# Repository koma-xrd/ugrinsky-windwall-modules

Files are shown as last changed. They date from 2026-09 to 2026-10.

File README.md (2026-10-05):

# Ugrinsky Wind Wall V5

> **AI-assisted design:** This model and its documentation were developed with
> generative AI assistance. They remain an unvalidated prototype and require
> physical fit, strength, weather, rotation, and electrical testing before use.

A parametric CadQuery project for a seven-stage vertical-axis rotor and an
experimental axial-flux generator mounted between two timber rails. The repository
contains editable CAD source, verified geometry exports, assembly drawings, and
complete assembly and coil-experiment manuals in six languages.

**V5 is a prototype awaiting physical validation.** Geometry checks do not establish
power output, a safe maximum speed, fatigue life, weather resistance, or suitability
for unattended operation. Begin with fit coupons and a guarded workshop test rig.
The generator must not be connected directly to a 48 V lead-acid battery.

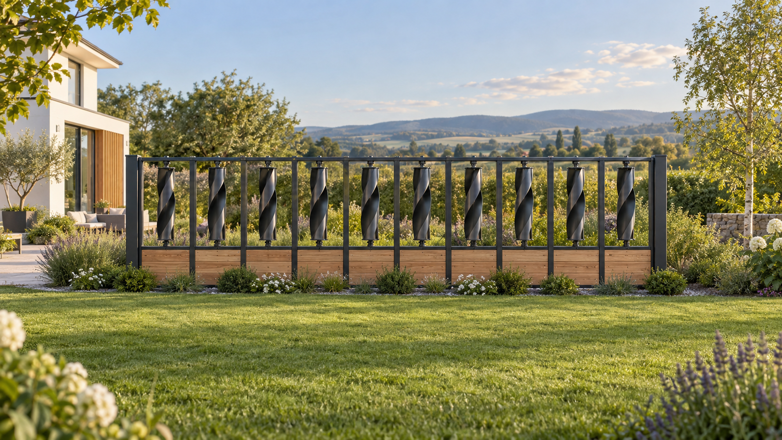
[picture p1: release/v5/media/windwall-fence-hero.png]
Realistic concept of a ten-rotor Ugrinsky fence beside a modern home and garden


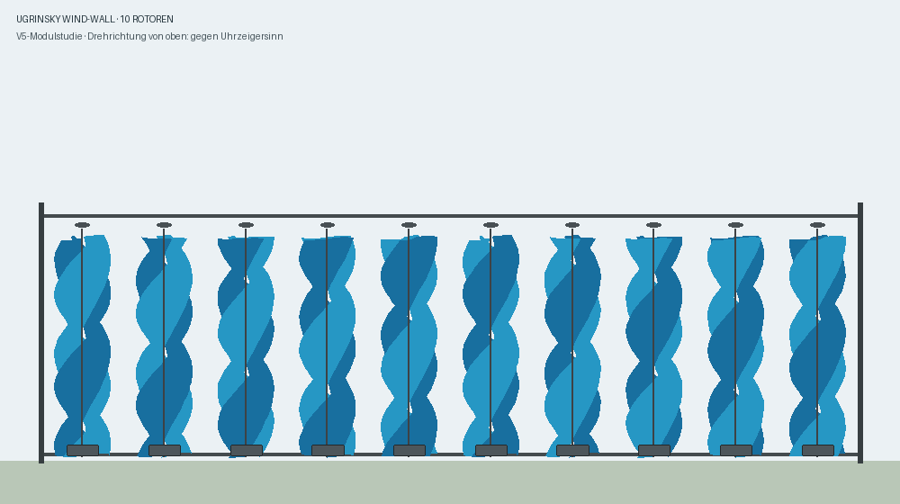
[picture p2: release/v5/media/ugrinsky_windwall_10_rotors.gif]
Animated ten-module Ugrinsky wall concept in a fence context


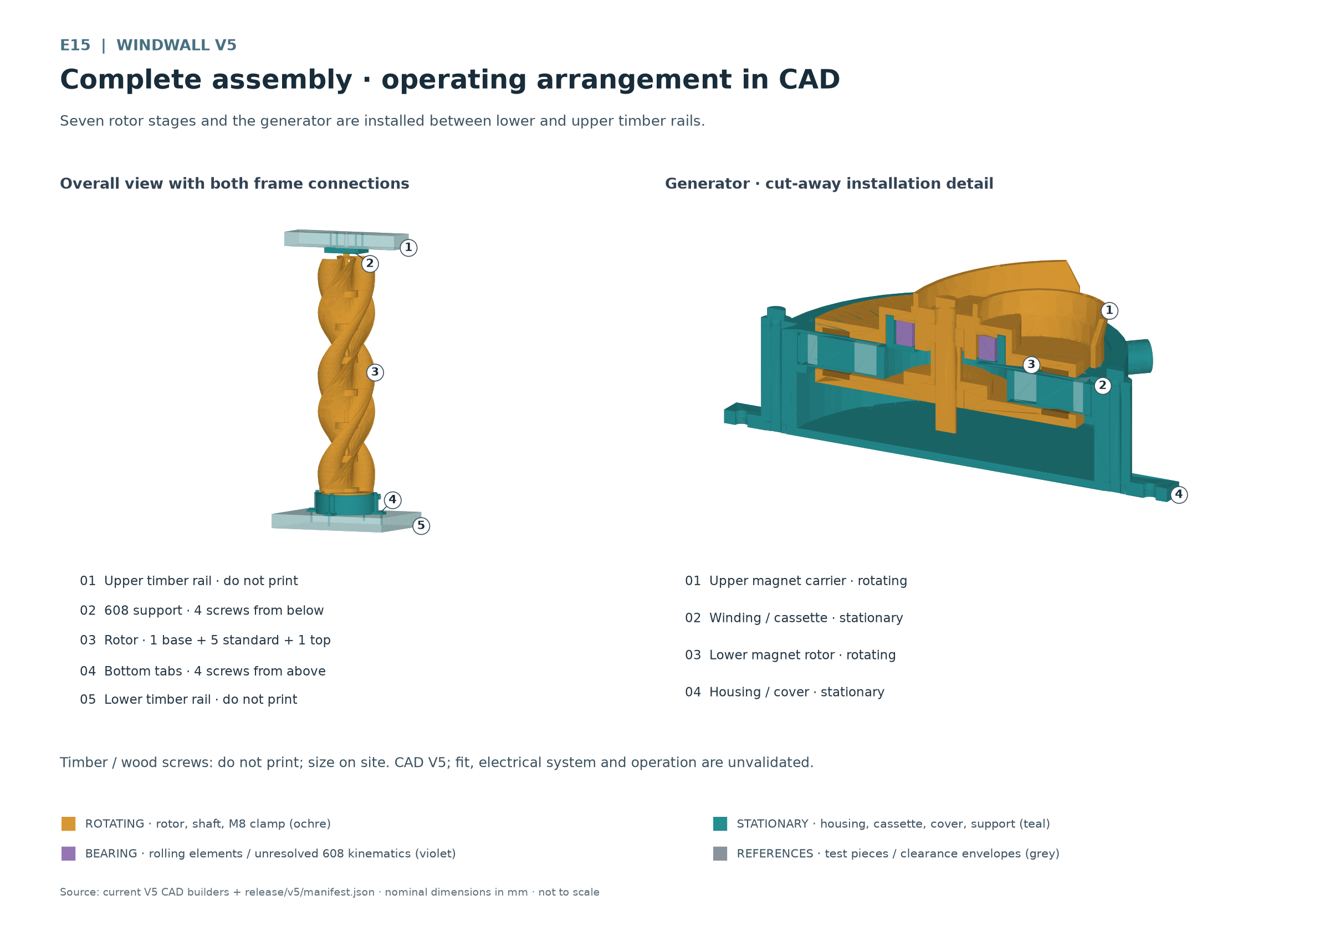
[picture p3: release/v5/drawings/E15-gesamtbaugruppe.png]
Complete V5 assembly between timber rails with rotating and stationary components distinguished


## Start here

The [release index](release/v5/release-index.json) is the complete portable inventory.
The [geometry manifest](release/v5/manifest.json) is authoritative for quantities,
dimensions, roles, file hashes, and CAD validation results.

| Assembly and experiment manual | Language |
| --- | --- |
| [English manual](release/v5/docs/Ugrinsky-Wind-Wall-V5-Manual-English.docx) | English · en-GB |
| [简体中文手册](release/v5/docs/Ugrinsky-Wind-Wall-V5-Manual-Chinese-Simplified.docx) | Simplified Chinese · zh-CN |
| [हिन्दी पुस्तिका](release/v5/docs/Ugrinsky-Wind-Wall-V5-Manual-Hindi.docx) | Hindi · hi-IN |
| [Manual en español](release/v5/docs/Ugrinsky-Wind-Wall-V5-Manual-Spanish.docx) | Spanish · es-ES |
| [Manuel en français](release/v5/docs/Ugrinsky-Wind-Wall-V5-Manual-French.docx) | French · fr-FR |
| [Deutsche Bauanleitung](release/v5/docs/Ugrinsky-Wind-Wall-V5-Bauanleitung.docx) | German source · de-DE |

Every manual preserves all 13 chapters, 11 tables and 15 current drawings. The five
translations include localized captions and complete alternative descriptions.
All manuals share the same canonical English E01-E15 engineering drawings.
Technical filenames remain unchanged.

The DOCX packages pass structural and accessibility checks. Rendering remains
blocked because bundled LibreOffice is unavailable on this Windows runtime; no PDF
or rendered-page approval is supplied. Pagination, clipping and Chinese/Hindi glyph
rendering require page-by-page visual review. No independent native-speaker review
is recorded.

## V5 architecture

The rotor has one base, five identical standard modules and one top module. Nominal
diameter is 122 mm, stage pitch is 70 mm and aerodynamic height is 490 mm. Each module
is one printed body with a 2 mm nominal blade wall. The base integrates the upper
magnet carrier. Adjacent stages have plain flush blade ends. The central bayonet
is the sole keyed torque interface; an M8 shaft and clamping hardware complete
the rotating assembly.

The lower magnet rotor has a flat 5 mm carrier print surface, a raised central
boss with a bottom-open M8 nut pocket, and an upper integral sleeve. Print the flat
carrier face on the bed; the pocket remains accessible from below. The rotor runs
inside the closed-bottom housing, below the stationary
coil cassette. A keyed shoulder seats the cassette; a screwed cover retains it
from above. The 51105 thrust bearing transfers rotor weight to the stationary cover
and housing. The upper 608 bearing provides radial guidance in a separate support
attached beneath the upper timber rail.

The base includes a 54 mm rotating labyrinth cup around the stationary 51105
bearing-seat ring. Its 49 mm internal diameter leaves 0.4 mm nominal radial
clearance, and its top cap leaves 0.25 mm nominal axial clearance above the ring.
Check free rotation and the printed clearances before running the rotor. This
shield does not establish waterproofing or weather resistance.

| Rotates with the shaft | Remains stationary | Bearing motion |
| --- | --- | --- |
| Base and integrated upper magnet carrier | Housing and mounting tabs | 51105 shaft washer rotates with the base |
| Five standard modules and top module | Coil and keyed cassette | 51105 housing washer stays in the cover |
| Lower magnet rotor, integral spacer sleeve and both magnet rings | Cover and its four M4 fasteners | 51105 rolling elements have their own motion |
| M8 rod, three nuts and top washer | Upper support and timber frame | 608 inner ring follows the shaft; outer ring stays in its support |

Purple bearing envelopes do not resolve individual rolling-element motion. Grey
timber and screw envelopes are references, not printable parts or structural approvals.

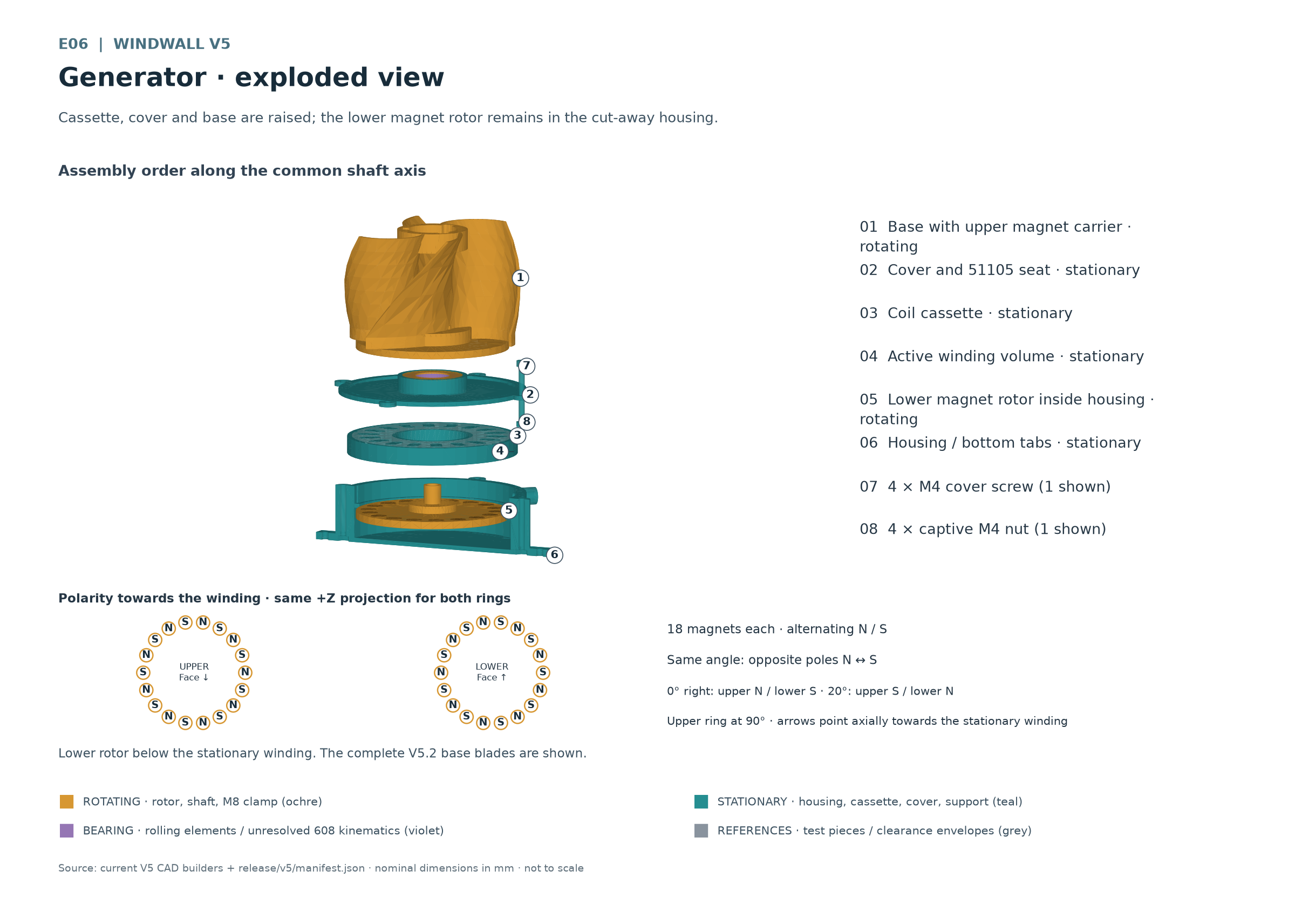
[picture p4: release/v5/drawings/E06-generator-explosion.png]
Generator explosion with top access and the lower rotor inside the housing


## Printed parts and hardware

One complete V5 needs **12 printed bodies from 8 unique STL files**. Production STLs
are in [release/v5/stl](release/v5/stl/); each has a same-stem STEP in
[release/v5/step](release/v5/step/). STLs sit at print Z = 0, which does not choose
the best support strategy or printing orientation.

| Qty | STL filename | Function | Motion |
| --- | --- | --- | --- |
| 1 | `base_rotor_module.stl` | Base, integrated upper magnet carrier and bearing pilot | Rotating |
| 5 | `standard_rotor_module.stl` | Intermediate rotor stages | Rotating |
| 1 | `top_rotor_module.stl` | Final stage and reinforced top clamp seat | Rotating |
| 1 | `lower_magnet_rotor.stl` | Lower carrier with integral 12 × 17.85 mm shaft sleeve | Rotating |
| 1 | `generator_housing.stl` | Closed cup, cassette shoulder, cable outlet and mounting tabs | Stationary |
| 1 | `coil_cassette.stl` | Removable carrier with 18 open serpentine guides and anti-rotation key | Stationary |
| 1 | `generator_cover.stl` | Cassette retention and 51105 housing seat | Stationary |
| 1 | `top_support.stl` | Upper 608 bearing support | Stationary |

Print the nine [coupon bodies](release/v5/coupons/) first:
`magnet_pocket_coupon.stl`, `51105_outer_seat_coupon.stl`, `25mm_pilot_coupon.stl`,
`608_seat_coupon.stl`, `coil_cassette_segment_coupon.stl`, `bayonet_male.stl`,
`bayonet_female.stl`, `joint_male.stl`, and `joint_female.stl`. Each also has a STEP.
Cut the male cassette arc free flush with its plate and deburr it before comparison.

| Qty | Purchased item | Selection notes |
| --- | --- | --- |
| 1 | M8 threaded rod | Extended shaft envelope 555.8 mm; establish actual cut length by dry assembly |
| 3 | M8 nuts | Two torque-transmitting nuts and one upper clamping nut |
| 1 | Top M8 washer | Nominal 24 mm outside diameter × 2 mm thickness |
| 36 | Magnets | Two rings of 18; target 10 × 2 mm; measure coating and actual dimensions |
| 1 | Complete 51105 thrust bearing | 25 × 42 × 11 mm, including both washers and rolling elements |
| 1 | 608 radial bearing | 8 × 22 × 7 mm |
| 4 each | M4 cover screws and captive hex nuts | Separate from the four frame screws; select length and head from the real grip |
| 4 | Lower timber screws | Reference 4 × 30 mm, flat head Ø9; site-specific selection required |
| 4 | Upper timber screws | Reference 4 × 40 mm; site-specific selection required |

Also provide enamelled copper wire, insulated leads, suitable soldering and
insulation materials, tested magnet retention, strain relief and edge protection.
Test compatibility with enamel, magnet coating and print material before adhesive
or potting. Nominal hardware envelopes are not procurement or load-rating approvals.

## Printing and bearing fits

Start with **PLA on a Bambu P2S with a 0.4 mm nozzle**. Use the actual filament's
profile. A 0.20 mm layer height is an unvalidated starting point; set temperature,
cooling, walls, infill and supports from coupons and the complete slicer preview.
Confirm continuous toolpaths in the 2 mm blade wall. Bayonet roofs and undercuts
need verified bridges or removable supports. Keep support residue and elephant
foot off mating surfaces. Compare normal and inverted base orientations because
its installed magnet pockets face downwards.

Print coupons, then a real two-stage joint, then the full set. Record joining force,
cracks, seam alignment and play. **ASA is the intended later outdoor material trial**;
repeat fit, warping, retention and load tests after changing material. ASA alone does
not establish weatherproofing or long-term outdoor suitability. Follow the actual
filament and printer processing and ventilation instructions.

| Interface | Current CAD nominal | Coupon choices |
| --- | --- | --- |
| 51105 stationary outer seat | Ø42.2 mm × 11.2 mm seat depth | Ø42.0 / 42.2 / 42.4 mm |
| 51105 rotating base pilot | Ø24.8 mm | Ø24.6 / 24.8 / 25.0 mm |
| 608 upper support seat | Ø22.2 mm × 7.2 mm seat depth | Ø22.0 / 22.2 / 22.4 mm |
| Magnet pocket | Ø11.0 mm × 2.0 mm deep | Ø10.8 / 11.0 / 11.2 mm |
| Cassette radial clearance | Verify keyed fit and cover retention | 0.30 / 0.35 / 0.40 mm |

These are fit experiments, not approved press fits. The 51105 housing washer stays
in the cover and the shaft washer rotates with the base; both raceways face the
rolling elements. Identify parts by actual geometry and manufacturer markings.
Apply fitting force only to the ring or washer being seated.

The upper 608 outer ring stays in its support; timber closes the upward-open seat.
An M8 threaded rod is not a ground bearing journal. Any locally prepared running
surface needs measurement, controlled machining and rechecking of diameter, runout
and remaining section. Avoid a second axial clamp at the upper bearing. A printed
shaft guide sleeve is not specified.

## Magnet polarity and gap reference planes

Each ring has 18 coil-facing poles. Alternate **N S N S** around the upper ring.
At the same angle in a common +Z projection, the lower coil-facing pole is opposite:
upper N faces lower S, then upper S faces lower N. Mark a reference pocket and check
faces after flipping a carrier. Confirm retention independently before each rotation
test; open pockets alone do not establish centrifugal retention.

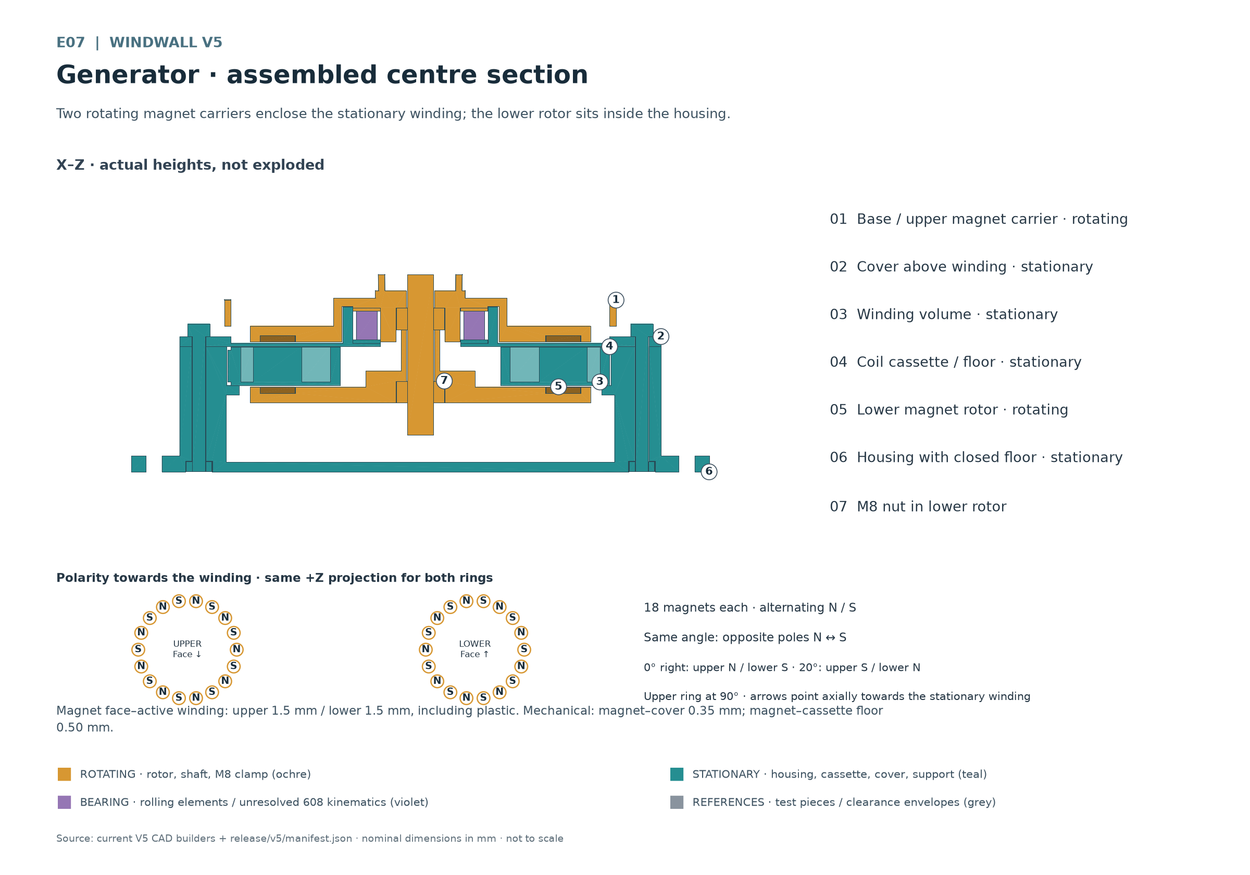
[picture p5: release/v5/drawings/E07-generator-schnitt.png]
Generator section showing rotating magnet rings around the stationary winding and both gap reference planes


| Distance | Nominal | Reference surfaces |
| --- | --- | --- |
| Upper magnetic distance | 1.5 mm | Upper magnet face to active winding face, including cover plastic |
| Lower magnetic distance | 1.5 mm | Lower magnet face to active winding face, including cassette-floor plastic |
| Upper mechanical clearance | 0.35 mm | Magnet face to cover membrane |
| Lower mechanical clearance | 0.50 mm | Magnet face to cassette floor |
| Membrane and cassette-floor thickness | 1.00 mm each | Plastic included in the magnetic distances |
| Cassette upward retention travel | 0.15 mm | Cassette top to cover underside |

The 1.5 mm values require flush or recessed magnets. Adhesive, protrusion, winding
height, axial float and runout can reduce the minimum clearance. Measure both gaps
over a full hand revolution and with available axial play. Contact-free CAD does not
prove clearance under load. Correct rubbing; never use higher speed to clear it.

## Assembly sequence

Use the full manual for tooling, checks and service. The essential order is:

1. Measure hardware, validate coupons and check magnet retention and polarity.
   Prepare an insulated, removable test coil and lead strain relief.
2. Seat four captive M4 nuts. Put the lower rotor, its M8 torque nut, shaft and
   integral sleeve inside the housing with magnet faces upwards. Keep nut and shaft clear of the floor.
3. Lower the cassette onto its shoulder, engage its key, align cable openings and
   route the protected cable.
4. Fit the stationary cover and tighten four M4 screws evenly in a crossing sequence.
   No PLA tightening torque is validated.
5. Install the 51105 housing washer, rolling elements and shaft washer correctly.
   Lower the base and upper torque nut, magnet faces down, controlling attraction
   with a fixture.
6. Check hand rotation and gaps. Add five standard modules and the top. Align the
   bayonet insertion windows, lock counterclockwise viewed from above, verify
   flush blade contact and inspect every latch. The dedicated bayonet fit uses
   0.20 mm nominal radial and 0.18 mm nominal axial clearance; its enlarged latch
   flank is intended to remain practically permanent after engagement. Reverse
   disassembly can damage the latch or module.
7. Fit the top washer directly on the flat upper plate and add the M8 nut; finish clamp adjustment before the upper bearing
   support. Do not bind stationary parts or bearings.
8. Fasten the housing's four tabs to the lower timber from above. Fit the 608 and
   fasten the upper support from below with four screws. Align both bearing axes;
   confirm full shaft engagement, end clearance and free rotation again.

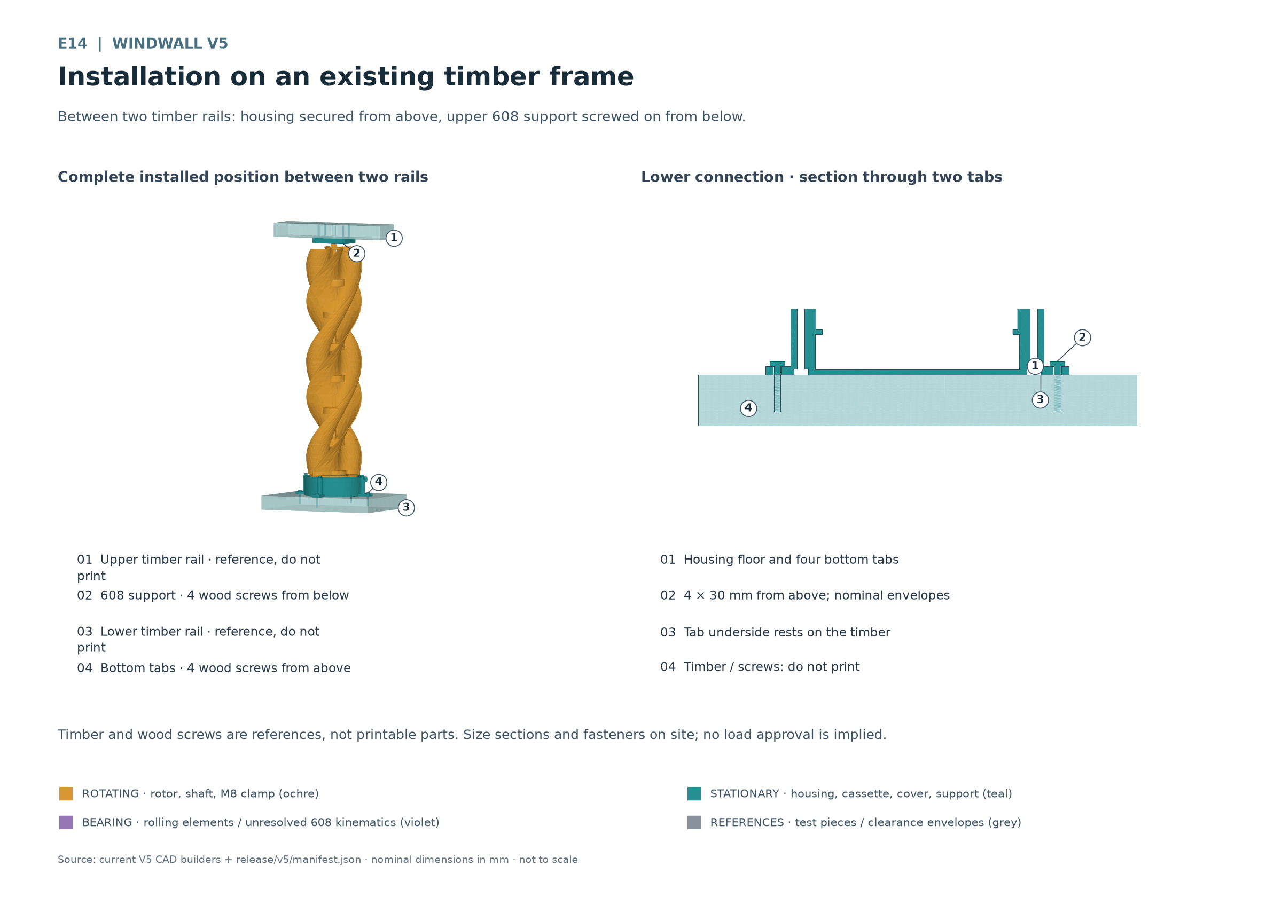
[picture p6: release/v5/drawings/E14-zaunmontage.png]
Fence mounting with lower housing screws downwards and upper support screws upwards


E14 timber sections and screw envelopes are examples. Frame strength, fixings,
edge distances and wind loading require site-specific engineering. The upper
support guides radially; the lower 51105 carries the intended axial load. Service
the cassette from above with the rotor stack supported as one unit; routine coil
changes should not require unlocking its six permanent stage joints.

## Serpentine coil experiments

Route insulated wire continuously around the cassette's 18 rounded open guide
islands, alternating past the inner and outer side of each successive island.
For this series, **one complete circuit of all 18 guides is one turn**. Mark start A,
end B and the path. With a few repetitions and hand rotation, verify
that successive active sections add voltage. Reversed sections or incorrect poles
can cancel it; the cassette does not define a validated electrical winding.

| Measured wire | Test turns | Keep comparable |
| --- | --- | --- |
| Initial 0.18 mm enamelled copper wire | 20 / 40 / 80 | Path, direction, recorded speed and defined load |
| Each future measured wire diameter | Repeat 20 / 40 / 80 | Measure conductor and enamelled outside diameter separately |

Record cold resistance, winding height, minimum gaps, speed, AC open-circuit
voltage, load value, loaded voltage/current, ambient and coil temperature, duration,
noise and vibration. Use instruments suited to the waveform. Rectifiers or pulsed
currents require appropriate DC or true-power measurement. Higher open-circuit
voltage does not establish useful loaded output. There is no final turn count or
validated power rating; each derived winding needs a physical test.

Do not connect directly to a 48 V lead-acid battery, even experimentally. A future
charging design needs measured electrical behaviour, rectification, compatible
charge regulation, reverse-current blocking, cable and short-circuit protection,
safe isolation and energy dissipation without a load. Any dump load needs thermal
and electrical design. No approved charging schematic is included.

## Serpentine coil winding tool

The [German build and operating guide](docs/serpentine-coil-winding-tool-de.md)
and [tooling release manifest](release/winding-tool/manifest.json) describe two
simple independent manual modules: a horizontal hand-cranked wheel with six open-top
contact shoes, and a free-running turntable for an upright wire roll. Both use the
same unchanged 190 × 190 mm base and one complete 51105 each. Print the common base
twice for simultaneous use. All six shoes use the same marked setting, from
100–200 mm in 10 mm steps. The wheel has 25 mm tape workspace below it. Remove the
top hex crank, then lift the taped coil upward with all shoes still seated.
The screwless PLA prototype has eight print masters and 14 printed occurrences.
Fits, strength, winding quality and operation require physical
testing. Akkuschrauberbetrieb ist nicht freigegeben.

The tooling release is isolated from the V5 production inventory and
`PRINT_SOURCES`. It includes the canonical BOM, current drawings and a synchronized
German guide; the manifest lists their hashes alongside the STL and STEP files.

Build the separate release with `python scripts/run_geometry.py scripts/build_winding_tool.py`.

## Repository and release layout

```text
src/windwall/              Parametric geometry, interfaces, validation and exports
scripts/                  CAD builds, previews, inspections and release indexing
scripts/manual/           German builder, figures and shared localization tools
scripts/manual/locales/   Five complete source-bound translation catalogues
tests/                    Geometry, export, drawing, manual and index regressions
docs/                     Design specifications, plans and measurement notes
release/v5/
  stl/                    Eight unique production meshes
  coupons/                Nine fit-coupon meshes
  step/                   Matching production and coupon solids
  assembly/               rotor_locked.step, generator.step, fence_assembly.step
  drawings/               E01–E15 PNGs, figures.json and drawing notes
  docs/                   German source and five translated DOCX manuals
  audits/                 German and multilingual structural/a11y evidence
  manifest.json           Geometry inventory and CAD audits
  release-index.json      Release files, sizes, hashes and validation bindings
build/                    Ignored previews, test outputs and rendering logs
reference/                External measurement references, not production meshes
```

Geometry uses `DesignParameters` and focused builders for blades, joints, generator,
bearings, housing and support. Assembly validation checks actual solids and exports,
identifying intentional contacts separately. `scripts/manual/manual_data.py` loads
release data without CAD. The German builder remains deterministic and independent
of localization.

The shared localization builder translates every source text run and figure
description while retaining layout, tables and image bytes. Catalogues bind to the
exact German DOCX hash. Coverage, numbers, technical filenames, language-specific
safety phrases and scripts are checked before writing. Explicit language metadata
and fonts use Arial for English/Spanish/French, Microsoft YaHei for Simplified Chinese
and Nirmala UI for Hindi.

## Build and test

Use Python 3.12 and [requirements.txt](requirements.txt) for CAD. From the repository
root, create or use the virtual environment. Every command importing CadQuery should
pass through the process-local Windows crash-dialog launcher:

```powershell
py -3.12 -m venv .venv
& ./.venv/Scripts/python.exe -m pip install -r requirements.txt
$env:PYTHONPATH = "$PWD;$PWD/src"
# Optional: set only to a real external reference file.
# $env:WINDWALL_REFERENCE_BLADE = '<reference-directory>/7 Ugrinsky_Blade.stl'
& ./.venv/Scripts/python.exe scripts/run_geometry.py -m unittest discover -s tests -v
$cadTestExit = $LASTEXITCODE
& ./.venv/Scripts/python.exe scripts/run_geometry.py scripts/build_v5.py --output-dir build/v5-check
$cadBuildExit = $LASTEXITCODE
Write-Output "CAD tests: $cadTestExit; CAD build: $cadBuildExit"
```

The optional reference enables the measured-source comparison. An unset variable
skips that test; a missing or wrong configured reference fails it. Keep downloaded
meshes external and retain their applicable source terms. Historical notes describe
their own stages; the V5 manifest and current manuals define this assembly.

A known native OCP shutdown failure can occur after passing assertions and valid
exports. Record the unittest result and process exit separately. The launcher
suppresses fault dialogs; it does not repair or conceal the native error.

DOCX creation and tests require the **bundled document Python returned by the Codex
workspace dependency loader**, separately from the CAD environment. On Windows:

```powershell
$documentRuntime = "$env:USERPROFILE/.cache/codex-runtimes/codex-primary-runtime"
$documentPython = "$documentRuntime/dependencies/python/python.exe"
& $documentPython -X utf8 scripts/manual/build_manual.py
& $documentPython -X utf8 scripts/manual/localize_manual.py
& $documentPython -X utf8 -m unittest tests.test_v5_manual tests.test_v5_i18n tests.test_release_index tests.test_v5_readme -v
& $documentPython -X utf8 scripts/manual/localize_manual.py --audit-only
```

Document authoring tests skip in the CAD runtime. The artifact-operation markers
for the German document and the five-document translation batch have already run;
do not repeat them for deterministic rebuilds. New artifact operations use the
document skill's marker once immediately before first authoring.

Run packaged accessibility/rendering QA, record evidence, then rebuild the index:

```powershell
& $documentPython -X utf8 scripts/manual/verify_translations.py
& $documentPython -X utf8 scripts/manual/localize_manual.py --audit-only --qa-directory build/manual-i18n-qa
& $documentPython -X utf8 scripts/index_v5.py
```

The QA wrapper restricts executable lookup to the bundle, preventing desktop
LibreOffice fallback. Missing rendering is recorded as blocked. When a bundled
document skill is installed outside the runtime tree, pass its resolved directory
with `verify_translations.py --document-skill-directory <directory>`. Verbose render
logs and temporary profiles stay in the selected QA directory. When a bundled
renderer becomes available, inspect every page and update the audit workflow to
record the new evidence; its current writer rejects unexpected render results.
Intermediates remain in `build/`.

Regenerating geometry or drawings can invalidate manual evidence. Review and rebuild
dependent documentation before publishing another index. The index checks geometry,
source manifests, all drawing hashes, the German manual, all five translations,
catalogue hashes, sizes, locales and structural evidence. Missing languages, stale
reviews, altered files and unlisted release artifacts are rejected. Index generation
does not confer physical approval or perform a new human review.

## Safety and remaining validation

Use a guarded rig, controlled drive and reliable stop. Keep people, hair, clothing
and loose objects clear. Stop for rubbing, cracks, magnet movement, vibration,
unusual bearing noise, heating or loose fasteners. Before each session check
retention, screw marks, insulation and free rotation.

The user reported that an earlier V4.3 bayonet coupon fits and closes; the current
tighter 0.20/0.18 mm coupon still requires a new test print. Assembly force and
fatigue life remain unmeasured. Rigid CAD motion sweeps encounter permanent
pawls and lug roofs during insertion. Elastic behaviour needs physical tests despite
installed-geometry clearance checks. The joint coupon's 4.2 mm open-spoke hex recess
is a calibration feature, not a full-depth load-bearing M8 nut socket.

Physical stiffness, bridge printability, dimensional fit, outdoor use and powered
operation remain unvalidated, including the flat lower carrier and plain blade joints.
Magnet retention, printed bearing fits, clamping, shaft alignment, strength, fatigue,
balance, electrical output, thermal behaviour, overspeed and frame loading remain
unvalidated. The side outlet and housing are not waterproof. Wind operation, UV,
frost, water exposure, charging and unattended continuous use require further
engineering and physical evidence. This repository makes no measured efficiency
or power claims.

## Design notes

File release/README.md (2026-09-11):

# Release packages

Printable and editable deliverables are grouped by release version. Use the
highest version unless a build note explicitly asks for an earlier prototype.

## Available releases

- [`v5/`](v5/) — current V5.2 prototype release

## Folder layout

Each version uses the same predictable structure:

| Folder or file | Contents |
| --- | --- |
| `stl/` | Ready-to-slice printable parts |
| `step/` | Editable CAD exchange files |
| `coupons/` | Small fit and joint test prints |
| `assembly/` | Complete reference assemblies |
| `docs/` | Assembly manuals and translations |
| `drawings/` | Exploded views and technical figures |
| `media/` | README and presentation images or animations |
| `audits/` | Generated review and translation evidence |
| `manifest.json` | Part dimensions, roles, and build metadata |
| `release-index.json` | File inventory and integrity hashes |

Start with the fit coupons before printing the complete rotor or generator.
The generated files remain prototype parts until their documented physical-fit
checks have been completed on the intended printer and material.

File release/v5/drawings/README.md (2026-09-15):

# V5-Montagezeichnungen

Die 15 PNG-Dateien E01–E15 sind mit 2400 × 1680 Pixeln aus den aktuellen
CadQuery-Volumenkörpern berechnet. Alle sechs Anleitungen verwenden dieselben
englisch beschrifteten Figuren mit nummerierten Bauteilmarkierungen und einer
gemeinsamen Bewegungslegende.
`figures.json` enthält Bild-ID, Dateiname, Bildunterschrift, Alternativtext,
Beschriftungen, explizite 3D-Merkmalsanker und 2D-Markierungsversätze, Pixelmaße,
CAD-Quellen, Bewegungszuordnung und dargestellte Grenzen. Bauteildatensätze enthalten
zusätzlich Druckbarkeit, Referenzhinweise und gegebenenfalls die Einschraubrichtung.
Die SHA-256 des verwendeten V5-Manifests steht im Kopf des Bildinventars.
Vor dem CAD-Aufbau vergleicht der Renderer die normalisierten angeforderten
Geometrieparameter mit diesem Manifest und weist Abweichungen zurück.

Erneut erzeugen, aus dem Repository-Verzeichnis mit aktivierter Python-Umgebung:

```powershell
$env:PYTHONPATH = '.;src'
python scripts/run_geometry.py -m scripts.manual.v5_figures
```

Eine andere Ausgabe wird mit `--output-dir build/v5-drawings` erzeugt. Der Renderer
importiert keine alten Zeichnungsbilder und ändert keine CAD-Bauteile. Die
Geometrie wird orthografisch projiziert; Schnitte entstehen durch CAD-Booleans.
Die Belichtung und Sortierung der Dreiecke sind deterministisch. Die seitliche
Beschriftung ist über Nummern mit dem Modell verbunden, ohne kreuzende Maßlinien.

| ID | Inhalt |
| --- | --- |
| E01 | Siebenstufiger Rotor, axial getrennte Vormontage |
| E02 | Base, Standard und Top mit glatten bündigen Blattenden |
| E03 | Zentrales Bajonett als einzige formschlüssige Drehmomentschnittstelle |
| E04 | Base-Schulter, M8-Mutter und getrennte 51105-Lagerteile im Schnitt |
| E05 | Unterer Magnetrotor im Gehäuse und Mittelschnitt mit planer 5-mm-Druckfläche, erhöhter unten offener M8-Tasche und oberer integrierter Hülse |
| E06 | Generator-Explosion mit unterem Rotor im Gehäuse unter der Wicklung |
| E07 | Montierter Generator im Mittelschnitt |
| E08 | Kassettenführung, Verdrehsicherung und axiale Rückhaltung |
| E09 | Deckel mit vier M4-Schrauben und gefangenen Muttern |
| E10 | Seitlicher Kabeldurchgang bei 45 Grad |
| E11 | Getrennte 51105-Außensitz- und 25-mm-Pilot-Coupons des Releases |
| E12 | 608-Lagersitz-Coupon mit drei Durchmessern |
| E13 | Oberer Halter: Schrauben von unten ins Holz; montierter Lagerschnitt |
| E14 | Einbau zwischen zwei Holzriegeln und Schnitt durch den unteren Laschenanschluss |
| E15 | Gesamtbaugruppe zwischen zwei Holzriegeln und Generator-Einbaudetail |

Ocker bedeutet rotierend, Türkis stationär. Violett kennzeichnet den separat
bewegten 51105-Wälzbereich beziehungsweise die unaufgelöste 608-Lagerhülle.
Grau kennzeichnet Prüf- oder Freiraumreferenzen. Das Holz ist als stationäre
CAD-Referenz grau dargestellt. Schrauben, Magnete, Wicklung und Lager
sind Nennhüllen. Es werden weder Gewinde noch elektrische Wicklungsdetails behauptet.
Magnete sind im rotierenden Ocker dunkler, der Wicklungsraum im stationären Türkis
heller dargestellt, damit ihre bündigen Grenzflächen erkennbar bleiben.
E06/E07 zeigen zusätzlich je 18 alternierende N/S-Polflächen beider Ringe in
derselben +Z-Projektion, 0 Grad rechts und 90 Grad oben. Beschriftet sind die zur
Wicklung gerichteten Flächen: oben nach unten, unten nach oben. Bei gleichem Winkel
stehen sich N und S gegenüber. Die Polbeschriftung verwendet keine zusätzlichen
Bewegungsfarben; `magnet_poles` hält Winkel, CAD-Flächenposition und Polrichtung fest.
Beide 1,5-mm-Abstände verlaufen von der Magnetfläche zur aktiven Wicklungsfläche
einschließlich der Deckelmembran oben beziehungsweise des Kassettenbodens unten.
Mechanisch bleiben Magnet–Deckel 0,35 mm und Magnet–Kassettenboden 0,50 mm frei;
der stationäre Kassetten–Deckel-Freigang zur Rückhaltung beträgt separat 0,15 mm.

E01 zeigt die Lage vor dem dauerhaften Einrasten, keine zugesicherte Demontage.
E04/E07/E15 begrenzen den oberen Blattbereich für die Detailansicht. E06 zeigt
den vollständigen Base-Körper. E05
blendet Kassette und Deckel zur Einsicht aus. E06 hebt Kassette, Deckel und Base
an; der untere Rotor bleibt in seiner Einbaulage. Die beiden E11-Coupons verwenden
dieselbe Trennung des kombinierten Builders an Y=0 wie der V5-Export.

E14/E15 ergänzen das unveränderte Produkt-CAD um zwei einfache Holzriegel und
untere Holzschrauben als **nicht druckbare Zeichnungsreferenzen**. Der untere
Riegel (Beispiel 260 × 190 × 30 mm) liegt an der Unterseite der vier Gehäuselaschen
an; vier nominale 4 × 30-mm-Schrauben mit flachem Kopf werden von oben eingedreht.
Ihre Achsen stammen direkt aus den vier CAD-Laschen. Der obere Riegel (Beispiel
260 × 70 × 30 mm) liegt auf dem vorhandenen 608-Halter; die vier 4 × 40-mm-
Schraubreferenzen des V5-Builders werden von unten eingedreht. Grau
unterscheidet diese stationären Holzreferenzen von den Druckteilen.
Holzquerschnitte, Schrauben, Vorbohrung und Tragfähigkeit sind vor Ort auszulegen;
die Nennhüllen behaupten keine Gewinde oder geprüfte Verbindung. Der obere Halter
wird erst nach dem Anziehen der M8-Klemmung montiert. Passung, Lagerung auf M8-Gewinde,
Magnetrückhaltung, elektrische Leistung, Festigkeit und Betrieb sind unvalidiert.

Die vorhandenen Vorschauprogramme für Rotorbaugruppe, Generator, Module und
Bajonett-Coupon verwenden nun die aktuellen V5-Schnittstellen. Die Rotorvorschau
teilt den Projektionsrenderer, stellt die offene obere M8-Klemmung dar und zählt
STEP-Volumenkörper getrennt von benannten Komponenten. Die Modulvorschau verwendet
die 60-Grad-Stufenphase. Rigid gemessene Rastüberdeckungen bleiben als ungeprüfte
elastische Passung dokumentiert. Die Programme schicken keinen Druckauftrag.

Auf dieser Windows/CadQuery-Laufzeit kann die native OCP-Nachbereitung nach
erfolgreicher Artefakterzeugung mit einem Fehlerstatus enden. Dateiprüfungen und
Testresultate müssen deshalb zusammen mit dem tatsächlichen Prozessstatus
berichtet werden; ein vorhandenes Bild allein belegt keinen sauberen Prozessabschluss.

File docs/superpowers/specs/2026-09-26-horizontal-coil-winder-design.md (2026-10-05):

# Horizontal 51105-supported coil-winder design

Date: 2026-09-26  
Status: Approved; implemented as a geometrically checked workshop prototype
Supersedes: the vertical coil-wheel module in
`2026-09-16-simple-pin-adjustable-coil-winder-design.md`

## 1. Purpose

Replace the unstable upright coil-wheel stand with a low horizontal winder. The
wheel rotates about a vertical axis on one 51105 thrust bearing, using exactly
the same unchanged printed base as the existing wire-payoff turntable.

The redesign retains the existing single-piece adjustable wheel, eleven marked
diameter settings from 100 through 200 mm, six removable contact shoes, and 18
tape stations. It removes the tall tower, both 608 bearings, their retainers,
the horizontal printed shaft, shaft collars, and the present side crank.

The result remains a PLA workshop prototype. Physical fit, bearing life,
powered operation, winding repeatability, and structural capacity are not
validated by the CAD model.

## 2. Approved layout

The coil wheel lies horizontally and rotates around a vertical central axis.
The stationary member is the existing `wire_payoff_base` master without any
geometric change. Its actual footprint remains 190 x 190 mm; the earlier
approximate 170 x 170 mm discussion is superseded by exact base reuse.

From bottom to top, the installed load path is:

1. bench;
2. unchanged `wire_payoff_base` floor and 51105 seat;
3. stationary lower 51105 washer;
4. 51105 rolling assembly;
5. rotating upper 51105 washer;
6. new printed horizontal-winder hub;
7. existing adjustable coil wheel; and
8. removable hand crank or a later low-speed driver bit.

The base owns the stationary washer and supports the full axial load. The hub
owns the rotating washer and carries the wheel. A long clearance-fit printed
pilot through the bearing and base bores provides radial guidance; the thrust
bearing is not claimed to locate radial load by itself.

If both tools are operated simultaneously, the BOM contains two occurrences of
the same printed base master and one 51105 bearing stack per tool. There is no
second base geometry or second base export.

## 3. Hub, wheel, and drive

The horizontal-winder hub is a new removable printed part. It interfaces with
the unchanged payoff base and canonical 51105 stack but does not need to match
the payoff platter or spool pilot. It must:

- seat positively on the rotating upper washer;
- use the base and bearing bores as a clearance-fit radial guide;
- provide a positive polygonal drive to the existing wheel;
- establish at least 25 mm clear vertical workspace between the underside of
  the wheel and the top surface of the base outside the central bearing boss;
- retain the wheel under gravity and normal downward winding force without
  fragile locking noses; and
- permit the wheel and hub to be lifted vertically for service.

The wheel-to-hub connection carries torque by shape, not by friction. A flat
axial stop defines the seated height. No screw, threaded rod, adhesive, or
permanent snap is part of the drive connection.

The upper drive interface is a centered female 1/4-inch hex socket sized for a
standard 6.35 mm male hex. The printed hand crank has a matching straight male
hex and is inserted and removed without a latch. Removing the crank leaves the
top of the wound coil unobstructed. The same socket may later receive a cordless
driver bit, but powered use remains explicitly unvalidated and restricted to
slow, controlled experiments.

## 4. Open-top contact shoes

The six shoes retain their current two-tongue friction mounting, numbered wheel
positions, rounded wire-contact surface, and three tape passages per shoe. Their
wire-contact profile changes for horizontal operation:

- the wheel-side lower edge remains a rounded supporting shoulder that prevents
  gravity-driven downward escape;
- the contact surface remains on the selected nominal winding radius;
- the upward edge is smoothly rounded but has exactly 0 mm radial projection
  beyond the nominal winding radius;
- there is no upper lip, centering shoulder, undercut, or other overhang; and
- every tape passage remains open through the final profile.

Gravity keeps the wire against the lower support during winding. After taping,
the finished coil must move straight upward over all six still-installed shoes.
The shoes are not moved inward and are not removed for normal coil release.

The central hub may remain installed during release because it lies inside the
open center of every supported coil. Only the hand crank or driver bit must be
removed before lifting the coil.

## 5. Tape access and operating sequence

The 25 mm minimum free space below the wheel is an operating clearance, not a
nominal overall tool height. The base has no new outer wall, guard, or support
that blocks access from any azimuth. The operator must be able to guide 10 mm
tape through each of the 18 existing passages and beneath the winding while the
wheel remains mounted on the bearing stack.

The normal sequence is:

1. place one unchanged payoff base and one 51105 stack on the bench;
2. install the horizontal-winder hub and adjustable wheel;
3. fit all six shoes at the same marked diameter;
4. insert the removable hand crank into the top hex socket;
5. wind by hand while guiding the wire and manually controlling the independent
   payoff turntable;
6. stop rotation and close all 18 tape wraps with the wheel still mounted;
7. remove the crank or driver bit;
8. lift the taped coil vertically over the six installed open-top shoes; and
9. inspect the wire insulation, shoe surfaces, hub, and bearing stack.

No step in normal release requires unplugging a contact shoe.

## 6. Ownership and release inventory

The horizontal winding module owns these printed occurrences:

- one `wire_payoff_base` occurrence, shared by exact master identity with the
  payoff module;
- one new horizontal-winder hub;
- one existing coil wheel;
- six identical revised open-top contact shoes;
- one removable hex hand crank; and
- one free-spinning rotating crank grip.

It owns one canonical purchased 51105 stack consisting of the two washers and
rolling member. It owns no 608 bearings, tower, bearing clips, shaft collars, or
upright-frame parts. Superseded upright-frame exports and BOM rows must be
removed from the winding-tool release once the replacement is implemented.

The payoff module remains otherwise unchanged. Exact base reuse must not alter
its geometry, fits, stability metadata, assembly, or service sequence.

## 7. CAD and verification requirements

Automated physical checks must cover all of the following:

- exact solid/master identity between the payoff base and the winding-module
  base;
- byte-identical payoff-base STL and STEP artifacts for both module occurrences;
- canonical 51105 washer ownership and axial load path;
- hub contact with the upper washer and base support beneath the lower washer;
- radial pilot engagement through the bearing and base bores without contact
  with the blind base floor;
- positive torque engagement between hub and wheel;
- at least 25 mm wheel-to-base working clearance outside the central boss;
- unblocked tape access at all 18 stations for 100, 150, and 200 mm coils;
- free slow rotation without wheel, hub, crank, base, or bench collision;
- six equal shoe placements at all eleven diameter settings;
- exactly 0 mm upper radial projection on every shoe contact profile;
- continuous collision-free upward release of taped winding surrogates at 100,
  150, and 200 mm while all six shoes remain seated;
- failure of the release audit when any upper lip or other trapping projection
  is introduced;
- hand-crank insertion, torque engagement, and straight withdrawal at the
  1/4-inch hex socket;
- printable orientation and the 220 x 220 mm bed limit for every unique master;
- valid single solids, manifold STL output, successful STEP reimport, and
  deterministic drawings, manifest, BOM, and artifact hashes; and
- complete removal of obsolete upright-frame inventory from the isolated
  winding-tool release.

Negative regression tests must reject a modified shared base, displaced 51105
members, insufficient radial pilot engagement, less than 25 mm tape workspace,
blocked tape passages, a retained upper shoe lip, an unseated wheel, and a drive
that depends only on friction.

## 8. Documentation and drawings

The German assembly guide and release drawings must show the horizontal
orientation, the exact shared payoff base, the 51105 stack order, the 25 mm
minimum work gap, top hex drive, tape routing, and straight-up coil release with
all shoes installed.

The guide must distinguish the two uses of the common base and state that two
printed occurrences are required for simultaneous winding and payoff. It must
also state that the 51105 parts are purchased bearing members, not printed
races.

## 9. Safety and validation limits

Manual operation is the validated design intent. A cordless driver may only be
described as a future low-speed option. The documentation must not assign an
approved speed, torque, duty cycle, or production use before physical testing.

The following remain unvalidated:

- actual PLA-to-bearing and pilot fits;
- printed hub and hex-drive strength;
- crank retention by straight plug fit;
- stability under real wire tension and operator force;
- smoothness and life of the 51105 in this application;
- enamel protection and achievable winding accuracy;
- tape access with the operator's actual tape and hand size;
- coil-release force; and
- cordless-driver operation.

Eye protection is required. Hair, clothing, fingers, loose wire, and tape must
remain clear of rotating parts. The operator must stop immediately if the hub,
hex drive, shoes, wheel, bearing seat, or base shows cracking, looseness, or
abnormal wear.

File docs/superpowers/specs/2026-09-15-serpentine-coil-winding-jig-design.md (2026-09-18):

# Serpentine Coil Winding Jig Design

Status: superseded by [the 2026-09-16 simple pin-adjustable coil-winder design](2026-09-16-simple-pin-adjustable-coil-winder-design.md).
This historical specification records the replaced mechanism; it is not the current build or operating guide.

## Purpose and scope

Add two independent, manually operated workshop modules for producing the
experimental 18-station serpentine winding used by the V5 generator cassette:

1. a centred, diameter-adjustable winding jig that first produces a flat round
   coil and exposes fixed positions for taping it, and
2. a passive payoff turntable for the enamelled-copper-wire supply spool.

The concept follows the workflow of the user-supplied Thingiverse reference
<https://www.thingiverse.com/thing:5941354>, but the geometry and mechanisms are
new, parametric parts matched to this repository's V5 coil cassette.

The first supported conductor is the existing 0.18 mm enamelled copper wire.
The tooling does not establish a final turn count, electrical rating, safe
rotational speed, or production-qualified winding process.

## Winding workflow

1. Set all six winding ribs to the required diameter with the central cam.
2. Lock the cam and place 10 mm tape strips in the 18 tape passages.
3. Anchor the wire without scraping or sharply bending its enamel.
4. Turn the hand crank while guiding the wire and allowing the separate supply
   spool to rotate under light, adjustable drag.
5. Close the 18 tape strips around the completed round coil.
6. Release the cam lock and retract the ribs by at least 2 mm radially.
7. Remove the taped coil and form it around the cassette's 18 alternating
   inner/outer guide positions.
8. Mark both leads and winding direction before fitting or testing the coil.

One circuit of all cassette guides remains one electrical turn, as defined by
the existing generator documentation.

## Adjustable winding head

### Geometry

- Six winding ribs are spaced at 60 degree intervals and move only radially.
- A concentric rotary cam plate moves all six ribs synchronously. Identical cam
  tracks and followers keep the winding contour centred on the drive axis.
- The supported nominal winding diameter is continuously adjustable from
  110 mm through 145 mm.
- A clearly engraved 127 mm index is the initial setting calculated from the
  current serpentine guide centreline. It is a prototype starting value, not a
  physically validated production dimension.
- A separate clamp locks the cam plate during winding. The clamp must not rely
  on follower friction alone.
- Captive mechanical end stops prevent every slider from leaving its guide at
  either adjustment limit.
- Unlocking and turning the cam inward provides at least 2 mm radial clearance
  from the wound diameter for coil removal.

The cam, slider, and rib interfaces are parameterised from one diameter value.
Public metadata reports the requested diameter, achieved rib radius, permitted
range, tape-station count, and release travel.

### Tape access

The head provides 18 visibly numbered tape stations at 20 degree intervals.
Each station has a passage at least 12 mm wide so a 10 mm tape strip can be
placed before winding and closed around the finished coil. Printed surfaces
must not trap the tape after the ribs retract. Tape passages, slider structure,
fasteners, and cam followers must remain mutually clear throughout the full
110--145 mm adjustment range.

All wire-contacting edges use generous radii or chamfers. No split line,
fastener end, or unsupported bridge may present a sharp edge to the enamel.

## Winding frame and drive

The winding axis is horizontal between two uprights on a stable table base.
Two standard 608 radial bearings support an 8 mm shaft. The adjustable winding
head is removable from the shaft and is retained by positive mechanical
fastening rather than a printed friction fit.

A hand crank with a freely rotating grip is the only approved drive for this
version. The shaft also includes a coaxial 6.35 mm female hex interface for a
future screwdriver bit. Providing the interface does not approve powered use;
the documentation must warn that speed, torque limiting, guarding, and safe
wire handling have not been designed or validated.

The base includes through-holes and accessible edge lands for either bench
screws or two clamps. The crank, head, and clamp controls must remain reachable
without placing a hand in the winding path.

## Wire-spool payoff turntable

The payoff unit is mechanically separate so the user can choose a low-friction
feed angle and distance.

- The rotating platter is nominally 150 mm in diameter.
- Its central spool pilot is 15 mm in diameter and 20 mm high, with a lead-in
  chamfer and no sharp wire-contacting edges.
- One existing 51105 thrust bearing (25 x 42 x 11 mm nominal) carries the axial
  platter load. Its housing washer remains stationary, its shaft washer rotates
  with the platter, and the rolling assembly remains separately identifiable.
- Printed bearing seats reuse the repository's explicit fit-clearance strategy;
  nominal dimensions are not represented as guaranteed printed press fits.
- A replaceable felt friction surface and spring-loaded adjustment provide
  light drag to prevent spool overrun. The adjustment must reach a free-running
  state and must not rigidly lock the platter during normal payoff.
- The spool remains removable without dismantling the bearing seat.
- A low, wide base includes the same screw/clamp mounting options as the winding
  frame.

The payoff turntable does not actively synchronize with the winding head. This
avoids transmitting a forced feed rate or damaging the 0.18 mm wire when the
operator pauses.

## Components and interfaces

CAD responsibilities are separated into focused modules:

- winding-head geometry: cam, followers, sliders, ribs, tape passages, limits,
  and diameter metadata;
- winding-frame geometry: base, uprights, 608 seats, shaft interfaces, crank,
  and head retention;
- payoff geometry: base, 51105 seats, platter, spool pilot, and drag mechanism;
- assembly and validation: placement, moving/stationary ownership, clearances,
  fastener inventory, and collision checks;
- export and documentation: printable bodies, STEP assemblies, drawings, bill
  of materials, operating sequence, and prototype warnings.

Existing bearing definitions are reused instead of duplicating 608 or 51105
nominal dimensions. New tooling parameters remain separate from generator
product geometry so experimental jig changes cannot silently alter the turbine.

Likely non-printed hardware consists of two 608 bearings, one 51105 bearing, an
8 mm shaft, metric fasteners and washers, a crank grip fastener, a cam-lock
fastener, six metal follower fasteners, springs, and replaceable felt. Exact
lengths and quantities are resolved in the implementation plan and then emitted
by the final bill of materials.

## Printable and release artifacts

The release includes:

- individual STL files for every printable part, oriented or documented for
  practical printing;
- STEP files for serviceable parts and complete assemblies of both modules;
- an exploded assembly view and dimensioned overview drawings;
- a German construction and operating guide;
- a hardware bill of materials;
- the calculated 127 mm setup and physical calibration procedure; and
- an indexed manifest matching the actual generated artifacts.

Large parts must fit a nominal 220 x 220 mm print bed without requiring the
user to split the 150 mm platter. No support-dependent hidden cavity may make a
bearing seat or tape passage impractical to print and clean.

## Validation and tests

Automated tests cover:

- valid, connected solids for every exported printable part;
- exactly six radial sliders with equal achieved radius at sampled settings;
- continuous adjustment and hard limits at 110 mm and 145 mm diameter;
- the marked 127 mm reference setting;
- at least 2 mm release travel;
- exactly 18 numbered, 20-degree tape stations with at least 12 mm clearance;
- absence of cam, follower, fastener, tape-passage, and frame collisions at the
  minimum, reference, and maximum settings;
- coaxial shaft, winding head, crank, and hex interface;
- two valid 608 seats around the 8 mm shaft;
- 150 mm platter and 15 x 20 mm spool pilot dimensions;
- correct moving/stationary ownership of all 51105 elements;
- drag-adjuster clearance and a non-locking free-running endpoint;
- print-bed envelope limits and complete STL/STEP/manifest exports; and
- agreement between CAD metadata, bill of materials, drawings, and guide.

Visual verification covers cam motion, tape insertion and closure access,
hand-clearance around the crank, coil release, supply-spool removal, practical
print orientation, and the assembled feed path. A physical prototype must
confirm the printed fits, useful drag range, enamel protection, 127 mm starting
diameter, and final fit on the generator cassette.

## Safety and limitations

The tooling is prototype workshop equipment. Long thin wire can cut skin,
tangle, snap, or unwind unexpectedly. Eye protection is required; loose hair,
clothing, and jewellery must be kept clear. The user must stop turning before
adjusting the cam, tape, drag brake, or wire path.

Powered operation is outside this version's validated scope even though a
standard hex interface is present. The winding head is not a flywheel-rated or
guarded rotating assembly. Printed bearing fits, strength, fatigue life, crank
loads, wire tension, and achievable winding quality require physical testing.

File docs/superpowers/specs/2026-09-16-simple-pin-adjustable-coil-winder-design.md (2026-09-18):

# Simple pin-adjustable serpentine coil winder design

Date: 2026-09-16  
Status: Approved in conversation; awaiting review of this written specification  
Supersedes: `2026-09-15-serpentine-coil-winding-jig-design.md`

## 1. Purpose

Replace the existing mechanically complex six-rib cam winder with a much simpler,
fully manual workshop jig inspired by the open, single-wheel layout of the
[Serpentine Coil Winding Machine](https://www.thingiverse.com/thing:6863041).

The new system has two independent modules:

1. a vertical hand-cranked coil wheel with six radially repositionable wire-contact shoes; and
2. a free-running horizontal turntable carrying the copper-wire roll upright.

The design is a PLA prototype for winding 0.18 mm enamelled copper wire. It is
not electrically, structurally, dimensionally, or operationally validated by
physical testing. Powered operation is outside scope.

## 2. Design priorities

In descending order:

1. simple construction and operation;
2. tool-free diameter adjustment and coil removal;
3. no screws, nuts, threaded rods, or metal shafts;
4. reuse of the available two 608 bearings and one 51105 thrust bearing;
5. printable parts within a 220 x 220 mm print bed;
6. replaceable wear parts rather than a permanently assembled mechanism.

## 3. Coil-wheel module

### 3.1 Layout

The coil wheel is vertical and accessible from the front. A compact single-sided
stand supports the wheel through two adjacent 608 bearings. This retains the
simple open layout of the reference while providing better resistance to tilt
than a single bearing.

The printable wheel is a single six-spoke part. Each spoke contains two parallel
radial rows of keyed holes. Six identical removable contact shoes plug into the
rows. Both pins on a shoe must engage the same numbered radial position, so the
shoe cannot rotate under wire tension.

### 3.2 Diameter range

The wheel provides eleven discrete nominal winding diameters:

`100, 110, 120, 130, 140, 150, 160, 170, 180, 190, 200 mm`.

Adjacent pin positions therefore differ by 5 mm in radius. Every position is
permanently and legibly marked on the wheel. All six shoes must use the same
numbered position.

The setting is the nominal envelope across the six wire-contact shoes. Because
the same short shoes serve all diameters, the wound form is a softly rounded
hexagon rather than a mathematically exact circle. This is intentional and
acceptable because the taped winding is subsequently reshaped into a serpentine
coil.

### 3.3 Contact shoes

Each of the six identical shoes has:

- two integral keyed insertion pins;
- PLA-compatible resilient retention tabs accessible from the rear;
- a short, shallow-convex wire-contact face;
- generous radii on every surface that can touch enamelled wire;
- three 12 mm clear tape passages for 10 mm tape; and
- no threaded or separate retention hardware.

Together the shoes provide 18 tape stations at a nominal angular pitch of 20
degrees. Small gaps between neighboring shoes remain open for handling and tape
access. The contact faces must not introduce sharp edges or local undercuts that
trap the finished winding.

### 3.4 Coil release

After all 18 tape wraps are closed, the operator releases each shoe from behind
and moves it at least one radial position inward or removes it completely. The
resulting reduction in support envelope must create at least 2 mm radial release
clearance everywhere around the winding. The taped winding is then removed
forward from the open wheel without withdrawing a shaft or opening a surrounding
frame.

### 3.5 Printed shaft and crank

The central shaft is fully printed in PLA. It uses 8 mm journals through the two
608 inner rings and increases to approximately 14 mm outside the bearing span.
Polygonal drive interfaces transmit torque to the wheel and crank without relying
on friction alone.

Printed snap collars provide bidirectional axial retention. Each collar, the
shaft, wheel, crank, and rotating grip remains individually removable and
replaceable without screws. Snap features must have accessible release faces and
must not require excessive bending for assembly.

The crank is for hand operation only. No drill-bit socket or powered-drive
interface is included in this simplified design.

### 3.6 Stand

The stand consists of a stable printable base and compact bearing tower joined by
positive snap features. It must:

- support the two 608 outer rings positively;
- retain the bearings without screws or adhesive;
- allow bearing removal without destroying the stand;
- remain stable throughout a complete crank rotation;
- leave the rear shoe latches accessible; and
- provide clamp lands or holes for optional bench clamping without making
  fasteners part of the product assembly.

## 4. Wire-roll turntable

The payoff module is independent of the coil wheel. The copper-wire roll stands
upright on a horizontal 150 mm diameter platter.

The platter has an integral central pilot 15 mm in diameter and 20 mm high. It
rotates freely on the existing 51105 thrust bearing. The lower bearing washer is
supported by the stationary base and the upper washer carries the platter. The
bearing washers remain separate purchased parts and are not replaced by printed
races.

The base, central printed spindle, bearing seat, and platter use tool-free
snap/plug interfaces. The platter must be removable for loading a roll. There is
no felt pad, spring, adjuster, or other brake. The operator stops the roll by hand.

The base provides a stable footprint and optional clamp lands. It must not tip or
drag against the rotating platter under the intended light wire tension.

## 5. Operating sequence

1. Inspect the printed shaft, snap tabs, contact shoes, and all wire-contact
   surfaces for cracks, burrs, or sharp edges.
2. Insert all six shoes at the same marked diameter.
3. Place three tape strips in each shoe, adhesive side prepared for later closure.
4. Place the copper-wire roll upright on the payoff platter.
5. Secure the wire start in a rounded, non-cutting start feature on one shoe.
6. Rotate the wheel only with the hand crank while guiding the wire manually.
7. Stop the payoff platter by hand when winding stops.
8. Close all 18 tape wraps and mark winding direction and leads.
9. Release and move all six shoes inward by at least one position, or remove them.
10. Remove the taped winding forward and form it into the serpentine layout.
11. Inspect the winding and jig after a test coil before making further coils.

## 6. Materials and printing

All printed parts are designed for PLA. Snap tabs use low preload, generous root
radii, and limited deflection appropriate to PLA rather than relying on long
living hinges. The shaft and latches are replaceable wear parts.

Print orientation must keep principal layer planes favorable for the shaft,
contact-shoe pins, and snap tabs. Wire-contact surfaces require cleanup and light
smoothing before use. No support scar may remain on a wire-contact surface.

Every unique printed master must fit within 220 x 220 mm in its documented print
orientation. The design must avoid splitting the wheel unless the completed
single-piece geometry cannot meet that envelope.

## 7. CAD and verification requirements

Automated checks must verify:

- all eleven diameter settings from 100 through 200 mm;
- six equal shoe radii at every setting;
- positive two-pin engagement and retention of every shoe;
- 18 open 12 mm tape passages at the assembled setting;
- rounded wire-contact surfaces;
- at least 2 mm release clearance after moving shoes inward;
- collision-free forward removal of winding surrogates at 100, 150, and 200 mm;
- full crank rotation without stand collision;
- positive radial and axial support of both 608 bearings;
- positive 51105 washer ownership and free platter rotation;
- 150 mm platter diameter and 15 x 20 mm pilot;
- every printed master within the 220 x 220 mm bed envelope;
- valid positive-volume CAD solids;
- closed, manifold STL exports without collapsed facets;
- successful STEP reimport;
- deterministic BOM, manifest, drawings, and artifact hashes; and
- no coupling to the V5 turbine production inventory or `PRINT_SOURCES`.

Negative regression tests must reject mismatched shoe positions, missing retention,
blocked tape passages, inadequate release, displaced bearings, inaccessible snap
tabs, and non-printable envelopes.

## 8. Deliverables

- parametric CAD source for both modules;
- STL and STEP for every unique printable part;
- STEP assemblies for the coil wheel and wire-roll turntable;
- exploded and operating drawings;
- deterministic BOM and release manifest;
- German print, assembly, adjustment, winding, release, and safety guide; and
- automated geometry, export, inventory, and regression tests.

Existing release files for the superseded cam/rib/frame design must be removed or
replaced so the release contains only the simplified approved design.

## 9. Safety and validation limits

The guide must state exactly: `Akkuschrauberbetrieb ist nicht freigegeben`.

The following remain unvalidated until physical prototype testing:

- printed 8 mm shaft strength and fatigue;
- PLA snap-tab life and retention;
- bearing press/snap fit;
- actual winding diameter and repeatability;
- enamel protection under wire tension;
- turntable stability and hand stopping;
- coil-release force; and
- suitability for continuous or production use.

Eye protection is required. Hair, clothing, fingers, and loose wire must be kept
clear of the rotating wheel and free-running payoff. The operator must stop if the
printed shaft, latches, shoes, or stand show damage.

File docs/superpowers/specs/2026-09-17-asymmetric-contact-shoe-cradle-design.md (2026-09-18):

# Gerundete Drahtführung mit freier Vorderschulter

## Ziel

Der steckbare `winding_jig_contact_shoe` erhält eine direkt konstruierte,
gerundete Drahtauflage mit einer hohen Schutzschulter an der freien Vorderseite.
Alle sechs Schuhe müssen sich bei fest gehaltener, geschlossener getapter
Wicklung kontinuierlich nach vorn entfernen lassen.

Der Wire-Payoff bleibt vollständig unverändert.

Diese Festlegung ersetzt die ursprünglich geplante höhere rückseitige Schulter:
Sie hätte beim Vorziehen die festgehaltene Wicklung durchdrungen, noch bevor die
Rastpins das 5 mm dicke Rad verlassen. Auch eine positive niedrige Hinterschulter
würde Drahtverformung voraussetzen. Der überarbeitete Weg verlangt weder eine
Verformung der Wicklung noch eine radiale Verlagerung eingerasteter Schuhe.

## Profil und Bezugsmaße

- Der Auflageboden und der gesamte radseitige Auslauf liegen auf dem gewählten
  nominellen Wickelradius. Die Einstellung 100 mm behält ihre nominelle
  100-mm-Hülle; der Schulterrand ist kein Durchmesserbezug.
- Die rad- beziehungsweise rückseitige Entnahmeseite hat genau 0 mm Überhöhung.
  Ihre axiale Endkante ist gerundet; es bleibt keine positive Sperrlippe.
- Die freie vordere Schutzschulter steht 2,5 bis 3,0 mm über dem Boden
  (Konstruktionswert 2,7 mm). Sie bewegt sich beim Vorziehen vom Draht weg.
- Beim Standard-Schuh reicht die nominale Auflage bis zur oberen Bandmündung
  bei Z=23,8 mm. Die gesamte
  9 mm breite Prüfwicklung bei Z=12,5..21,5 mm liegt auf nominalem Radius.
  Die tangential anschließende kubische Rundung steigt bis Z=26,5 mm zur
  Vorderschulter an. Axiale Endabstände folgen der Bandfreiheit, damit auch
  akzeptierte kürzere Schuhe keine rückläufige Außenkontur erhalten.
- Boden, Übergang und Schulter sind stetig gerundet. Es gibt keine scharfen
  Kanten im Drahtkontaktbereich.
- Das Profil ist Bestandteil des einteiligen Schuhmasters. Es gibt kein
  separates Einsatzteil und keine einzelnen Führungsnasen.

## CAD-Konstruktion

Die asymmetrische Außenkontur wird direkt im axial-radialen Querschnitt der
Schuhschale beschrieben und anschließend als zusammenhängende Schalenkontur
erzeugt. Sie wird nicht als nachträglicher zylindrischer Ausschnitt in die
bisherige Schale eingebracht.

Die innere Schalenwand, der Schuhfuß und beide Rastpins behalten ihre bisherigen
Lagen und Schnittstellen. Dadurch bleibt der Schuh mit dem Fuß verbunden und
passt weiterhin in alle vorhandenen Lochpositionen des Wickelrades.
Die nominale Auflage wird getrennt von der zulässigen Schulterüberhöhung
physisch geprüft; die Rotationseinhüllende umfasst den gesamten Schulterrand.

## Klebeband und Entnahme

- Alle drei Klebebandpassagen pro Schuh bleiben mindestens 12 mm breit in
  tangentialer und axialer Richtung.
- Die Passagen bleiben vollständig frei. Der radiale Fräser reicht bis zur
  höchsten Schulter plus 0,4 mm Überlauf (3,1 mm); Überlauf ist keine zusätzliche
  zugesicherte Nutzfreiheit. Es bleibt keine Restwand vor dem Klebeband.
- Das bestehende Prüfmodell verwendet weiterhin geschlossene Streifen mit
  10 mm tangentialer Breite, 4 mm radialer Stärke und 10 mm axialer Höhe bei
  0,25 mm Wandstärke.
- Die feste Drahtprüfhülle bleibt 9 mm axial breit mit 1 mm radialem Aufbau
  und 0,02 mm innerem Abstand zur nominalen Auflage. Bei größeren Einstellungen
  enthält sie die geraden gespannten Verbindungen zwischen den Kontaktbögen.
- Nach dem Lösen müssen alle sechs Schuhe bei 100, 150 und 200 mm kontinuierlich
  nach vorn entfernt werden können. Danach muss die gebundene Spule nach vorn
  austreten können.
- Nach dem Lösen beider Zungen wird jeder Schuh 40 mm rein axial vorgezogen,
  vollständig entspannt und anschließend 40 mm radial außen geparkt. Alle
  sechs Schuhe bleiben als getrennte Servicekörper vorhanden.
- Erst danach wird die feste Wicklung samt 18 geschlossenen Bandhüllen 120 mm
  nach vorn entnommen. Rad, Welle und Ständer bleiben montiert.
- Jede vollständige Translation wird kontinuierlich geprüft, zusätzlich zu
  Zwischenstellungen. Nachbarschuh-, Band-, Rad- und Ständerkollisionen sowie
  Hindernisse zwischen den Endpunkten müssen die Freigabe verhindern.
  Drahtdehnung, Bandschlupf oder radiale Schuhentlastung sind keine Annahmen.

## Druck und Freigabe

- Der Schuh bleibt ein einzelner gültiger, geschlossener und manifold
  druckbarer Körper aus PLA.
- Die bisherige Druckorientierung und das 220-mm-Druckbett bleiben gültig.
- Geänderte Schuh-, Baugruppen-, Zeichnungs- und Manifest-Artefakte werden
  deterministisch neu erzeugt.
- Der bestehende Wire-Payoff und die V5-Freigabe müssen byte-unverändert bleiben.
- Die digitale Freigabe ersetzt keine physische Prüfung von Drahtschutz,
  Passung, Entnahmekraft, Rastlebensdauer oder PLA-Ermüdung.

## Abnahmekriterien

1. Regressionen schlagen am Profil mit hoher Hinterschulter fehl und bestätigen
   nominalen Auslauf, hohe Vorderschulter und feste Wicklung ohne Kollision.
2. Alle elf Durchmessereinstellungen behalten identische Schuhgeometrie und
   korrekte Lochzuordnung.
3. Sämtliche Band-, Nachbarpassagen-, Mesh-, STEP-, Druckbett- und
   Entnahmeprüfungen bestehen.
4. Zwei vollständige Neuaufbauten liefern identische Release-Dateien.
5. Anleitung und Zeichnungen zeigen und benennen den nominalen hinteren Auslauf
   und die hohe freie Vorderschulter wahrheitsgemäß.

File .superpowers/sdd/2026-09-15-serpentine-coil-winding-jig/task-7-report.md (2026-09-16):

# Task 7 report — workshop drawings, German guide and release

Status: implementation, release build, visual inspection and focused
verification complete. Commit subject: `docs: publish serpentine winding tool release`.

## Scope and implementation

- Added `scripts/preview_winding_tool.py`: three deterministic 2000 × 1400 PNGs
  from copied CAD meshes, fixed orthographic cameras, DejaVu Sans, fixed colors,
  stable depth sorting, bounded planar triangles and fixed PNG metadata.
- Added the complete German source guide, including 13 print-master rows
  (24 pieces), all 38 hardware BOM rows, print orientation/support caveats,
  assembly, mounting, bearing ownership, brake adjustment, winding/taping,
  radial release, forming, physical calibration and Probespule inspection.
- README links the guide and isolated tooling manifest, names both independent
  manual modules and distinguishes them from V5 production parts.
- The tooling exporter regenerates marked configuration/BOM tables from its
  authoritative parameters/BOM, copies the guide, renders the three drawings,
  hashes all four supporting artifacts and only then publishes the manifest.
  The default release guide matches the complete source guide exactly.
- The existing exploded-jig STEP presentation now separates the head groups
  farther and lifts each 608 above its upright. The same translated bodies
  feed the drawing, with every translation recorded in the manifest. No
  operating geometry, parts, assembly ownership or clearance audit changed.
- Matplotlib version is recorded with the existing pinned CAD runtime.
  No new dependency, V5 inventory/exporter change or PRINT_SOURCES entry.

Changed source files: `.gitattributes`, `README.md`, `docs/serpentine-coil-winding-tool-de.md`,
`scripts/preview_winding_tool.py`, `src/windwall/winding_tool_export.py`,
`tests/test_winding_tool_export.py`, this report, and the generated
`release/winding-tool/**` files.

## Strict TDD evidence

Working directory for all commands:
`C:\Users\fi87roy\Documents\GitHub\windwall\.worktrees\serpentine-coil-winding-jig`.
Interpreter: `C:/Users/fi87roy/Documents/GitHub/windwall/.venv/Scripts/python.exe`.
Environment: `$env:PYTHONPATH = "$PWD;$PWD/src"`.

Before implementation:

```powershell
& 'C:/Users/fi87roy/Documents/GitHub/windwall/.venv/Scripts/python.exe' scripts/run_geometry.py -m unittest tests.test_winding_tool_export.WindingToolExportTests.test_release_includes_synchronised_drawings_and_german_guide -v
```

RED: **1 test, FAILED (failures=1), 212.672 s**, status 1. The expected
`assertTrue(all((destination / name).is_file() for name in required))`
failed because the three PNGs and guide copy did not exist. This was a real
export followed by the inventory assertion, not a missing import or mock.

The new test also checks all support hashes, PNG signatures/native dimensions,
source/release guide synchronization, every BOM quantity/ID in the guide and
the exact one-for-one release file inventory. The existing failure-publication
test now includes the supporting-artifact boundary. Existing fresh-build tests
compare all artifact bytes, so they also cover drawings, guide, BOM and manifest.

## Generated STEP diff ruling and regression

Full staged whitespace review initially reported the native OCCT formatter's
trailing spaces in generated STEP syntax. Source, guide, JSON and binary-artifact
checks were clean. Parent ruling: add only
`release/winding-tool/**/*.step -diff`; preserve exact validated STEP bytes and
hashes, and leave V5 attributes untouched. The existing `-text` preserves bytes
on checkout; the new `-diff` treats generated CAD as binary for textual review,
which also suppresses STEP textual whitespace diagnostics. It is not a STEP
normalization or a claim that OCCT's textual output has no trailing spaces.

Before adding the attribute, added and ran a regression using real
`git check-attr diff` for two tooling STEP paths, a V5 STEP, the tooling guide
and the exporter source:

```powershell
& 'C:/Users/fi87roy/Documents/GitHub/windwall/.venv/Scripts/python.exe' scripts/run_geometry.py -m unittest tests.test_winding_tool_export.WindingToolReleaseAttributeTests -v
```

RED: **1 test, FAILED, 0.044 s**; tooling STEP values were `unspecified`
instead of `unset`. After the exact scoped attribute, GREEN: **1 test, OK,
0.052 s**. Both processes returned native status 1. The regression confirms
V5 STEP, documentation and Python source still have unspecified diff attributes.

## Visual inspection and corrections

All images are 2000 × 1400 pixels, inspected with local image tooling in
`original` detail mode. No generated image or hand-drawn substitute was used.

The first preview exposed head-group occlusion in the inherited exploded
presentation. Increased the head separation, moved both 608 envelopes above
their seats and adjusted only the fixed exploded camera; regenerated and
inspected the result. An initial Matplotlib cache warning was resolved by
using the existing writable `build/matplotlib` location before import.

- Reference: separate A/B bases are clearly visible with ample space between
  them. The Ø127 label, six-rib/cam callouts, two-608 note, 150-mm platter,
  15 × 20-mm pilot and schematic B → A wire-feed arrow are legible. Rib side
  windows are visible; the assembled 51105 is intentionally under the platter
  and referred to the exploded bearing view. Text is outside the CAD panel;
  no text is clipped or overlaps another label.
- Range: three distinct actual head builds at 110/127/145 mm show six
  concentric radial ribs and changing cam-track positions. Each panel has
  18 legible external station numbers at 20° intervals and all three contact
  circles. The counterclockwise winding arrow is unambiguous. The front view
  shows the contour; the side-window depth is visible in the reference view.
  Tape-width/passage and 2-mm radial-release text remains separate below.
- Exploded: head clamp, cam, six rib/slider groups, backplate, frame/shaft and
  crank are identifiable in the upper panel. Both purple 608 envelopes are
  lifted clear of the upright seats. Lower panel separately shows base,
  housing washer, rolling envelope, shaft washer, platter/pilot and brake
  group. Callouts 11–13 explicitly describe one complete 51105 and its motion
  ownership. Some hardware remains with its service group, as stated in the
  legend; this is not an individual-fastener disassembly drawing. Numbered
  markers and separate text columns are readable and unclipped.

## Release build and independent inventory audit

```powershell
& 'C:/Users/fi87roy/Documents/GitHub/windwall/.venv/Scripts/python.exe' scripts/run_geometry.py scripts/preview_winding_tool.py
& 'C:/Users/fi87roy/Documents/GitHub/windwall/.venv/Scripts/python.exe' scripts/run_geometry.py scripts/build_winding_tool.py
```

Final preview and release runs both printed their completion messages; the
release reported **13 unique print candidates and 3 STEP assemblies** and
published its manifest. Both subsequently returned native process status 1.
This is application completion, not a claim of clean native shutdown.
All three final release PNGs were then inspected again in original detail.

Independent PowerShell verification loaded the manifest/BOM, enumerated every
actual file, recomputed SHA-256 for each referenced artifact, checked every
BOM row against the guide and compared preview versus release PNG hashes:

```text
PASS: 35 exact files; 34 hashes; 13 print masters; 38 hardware rows;
source guide identical; 3 preview/release PNG pairs byte-identical.
```

The 35 files are 13 STEP/STL pairs, three assembly STEPs, `bom.json`,
`manifest.json`, the three named PNGs and the German guide. The manifest is
the one file without a self-hash. The two independent render paths agree even
though the full release previously tessellates the source solids for export.
The existing `test_fresh_builds_have_identical_artifact_bytes` also passed:
two fresh complete exports with an unrelated export between them produced
identical bytes for every emitted file, including BOM, drawings, guide and
manifest. This is independent of the preview/release PNG-only comparison.

`git diff --cached --check` passed for all staged sources and artifacts after
the explicitly recorded STEP attribute ruling; source-only checks also passed.
A diff against Task 6
for `src/windwall/export.py`, `scripts/build_v5.py` and `release/v5` was empty.
No Task 8 full-suite, merge or push was requested or performed by this task.

## Final focused GREEN and handoff

```powershell
& 'C:/Users/fi87roy/Documents/GitHub/windwall/.venv/Scripts/python.exe' scripts/run_geometry.py -m unittest tests.test_winding_tool_export -v
```

Result: **8 tests, OK, 1270.140 s**, followed by native process status **1**.
All CLI, failure-publication, complete-release determinism, drawing/guide
inventory, STEP reimport, BOM/hash, unique-master and rib-STL tests passed.
The scoped Git-attribute regression was added while this long run was already
active and therefore ran separately with the RED/GREEN result above. Together
the runs cover all **9 tests in the final focused module**, with no skipped or
failed tests. No clean native shutdown is claimed.

`git diff --check`, source-only `git diff --cached --check` and full
`git diff --cached --check` passed. The exact release inventory and every hash
were independently checked after the final build, and all final PNGs were
inspected at native resolution. No generated STEP bytes were normalized.

The report is committed with the implementation. Resolve the containing commit
without a self-referential hash using:

```powershell
git log -1 --format=%H -- .superpowers/sdd/2026-09-15-serpentine-coil-winding-jig/task-7-report.md
```

The final handoff records the resulting full commit hash and the post-commit
`git status --short` result. Next step: parent Task 7 review; Task 8 remains
outside this subtask.

## Limitations

Workshop prototypes only. No physical fit, strength, electrical, speed,
production or powered-operation validation is supplied. Supports, bearing
fits, custom hardware, wire enamel protection, useful brake drag, physical
Ø127 calibration and cassette fit require measured prototypes. The guide and
drawings state exactly: `Akkuschrauberbetrieb ist nicht freigegeben`.

The known native OCP shutdown can return status 1 after Python reports
success; application/unittest results and process status are reported separately.

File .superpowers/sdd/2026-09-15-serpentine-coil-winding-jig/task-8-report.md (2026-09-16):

# Task 8 report — release verification and integration readiness

## Scope and environment

Worktree: `C:\Users\fi87roy\Documents\GitHub\windwall\.worktrees\serpentine-coil-winding-jig`.
Branch: `codex/serpentine-coil-winding-jig`. Implementation examined: `e758c0f`.
Comparison baseline: `0fbebe9` (recorded branch start).
Interpreter: `C:/Users/fi87roy/Documents/GitHub/windwall/.venv/Scripts/python.exe`.

Read the Task 8 brief, complete implementation plan and design specification,
progress ledger, Task 6/7 reports, all six tooling source modules, both tooling
scripts, all six tooling test modules, changed export regressions, assembly
contract, German guide, README changes, and Git attributes. No additional
AGENTS.md was present in this worktree or its repository/worktree ancestors;
the supplied engineering guidelines apply.

This task adds this verification report only. The cleanup review found no
justified source, test, dependency, or generated-artifact change. No behavior
changed, so no new regression or separate focused cleanup rerun was needed.
No merge, push, whole-branch review, physical build or powered trial was started.

## Complete suite

From the worktree root:

```powershell
$env:PYTHONPATH = "$PWD;$PWD/src"
& 'C:/Users/fi87roy/Documents/GitHub/windwall/.venv/Scripts/python.exe' scripts/run_geometry.py -m unittest discover -s tests -v
```

Final unittest output:

```text
Ran 274 tests in 3526.968s

OK (skipped=22)
```

**252 passed, 22 skipped, zero failures/errors.** All winding-tool tests ran
and passed, including all three nominal diameter audits, deliberate collision
and displaced-engagement regressions, service access, failure-publication,
complete-release byte reproducibility, artifact inventory, and rib STL checks.

The skips are existing environment conditions, not passing tests:

- 1 blade-profile comparison: `External reference path not configured`.
- 10 `test_v5_i18n.V5TranslationTests` cases: `DOCX authoring requires bundled document Python`.
- 11 `test_v5_manual.V5ManualTests` cases: `Run manual tests with the bundled document Python; see README`.

This required CAD-interpreter run therefore did not execute the external-reference
comparison or those 21 Word-document authoring tests. No document runtime or
external reference was substituted, and no V5 document source changed.

After unittest printed `OK`, the process returned **status 1**, the known native
Windows/OCP teardown status. The unittest result is successful with skips;
the native process exit is not clean. The launcher preserves failure statuses,
and no exit code was intercepted or rewritten.

## Real CLI rebuild and release comparison

The existing release was moved only after resolving and checking both absolute
paths. The original release contained 35 tracked files and the backup did not
already exist. PowerShell performed both the move and later removal:

```powershell
$task8Root = (Resolve-Path -LiteralPath '.').Path
$task8ExpectedRoot = 'C:\Users\fi87roy\Documents\GitHub\windwall\.worktrees\serpentine-coil-winding-jig'
if ($task8Root -ne $task8ExpectedRoot) { throw 'Unexpected worktree' }
$task8Release = (Resolve-Path -LiteralPath 'release/winding-tool').Path
$task8Backup = [IO.Path]::GetFullPath((Join-Path $task8Root 'build/task-8-winding-tool-backup'))
if ($task8Release -ne (Join-Path $task8Root 'release/winding-tool')) { throw 'Unexpected release path' }
if (-not $task8Backup.StartsWith($task8Root + '\') -or (Test-Path -LiteralPath $task8Backup)) { throw 'Unsafe or existing backup' }
Write-Output "Verified source: $task8Release"
Write-Output "Verified backup: $task8Backup"
Move-Item -LiteralPath $task8Release -Destination $task8Backup
$env:PYTHONPATH = "$PWD;$PWD/src"
& 'C:/Users/fi87roy/Documents/GitHub/windwall/.venv/Scripts/python.exe' scripts/run_geometry.py scripts/build_winding_tool.py
```

The real CLI printed:

```text
Winding tool: 13 unique print candidates, 3 STEP assemblies.
Manifest: C:\Users\fi87roy\Documents\GitHub\windwall\.worktrees\serpentine-coil-winding-jig\release\winding-tool\manifest.json
```

Application publication completed. Native process status was **1** afterward,
consistent with the previously recorded Windows/OCP teardown limitation. This
is not described as a clean process exit or suppressed by a wrapper.

For both resolved trees, `Get-ChildItem -LiteralPath ... -File -Recurse` produced
relative paths through `[IO.Path]::GetRelativePath`, normalized to `/` and
sorted. `Compare-Object` found no inventory difference. Each pair was checked
using both exact byte comparison and SHA-256:

```powershell
foreach ($task8Relative in $task8OldPaths) {
    $task8OldFile = Join-Path $task8Old $task8Relative
    $task8NewFile = Join-Path $task8New $task8Relative
    $task8Before = [IO.File]::ReadAllBytes($task8OldFile)
    $task8After = [IO.File]::ReadAllBytes($task8NewFile)
    if (-not [Linq.Enumerable]::SequenceEqual[byte]($task8Before, $task8After)) { throw "Byte mismatch: $task8Relative; preserve backup" }
    if ((Get-FileHash -LiteralPath $task8OldFile -Algorithm SHA256).Hash -ne (Get-FileHash -LiteralPath $task8NewFile -Algorithm SHA256).Hash) { throw "Hash mismatch: $task8Relative" }
    $task8ByteCount += $task8After.LongLength
}
```

Exact output from the independent PowerShell checks:

```text
PASS: 35 identical paths; direct byte equality and SHA-256 equality; 36591723 bytes per tree
PASS: exact manifest/tracked/file inventory; 34 verified manifest hashes; no extras
PASS: 13 print masters, 24 pieces, 38 hardware rows; source/release guide bytes identical
```

The inventory comprises 13 part STEP/STL pairs, three assembly STEPs, three
PNGs, the German guide, BOM and manifest. All 35 files, including the manifest's
audit records and runtime metadata, matched exactly. Independently reconstructed
the 34 artifact references from `printable_parts`, `assemblies`,
`supporting_artifacts` and `bom_path`; recomputed all their hashes and compared
that inventory plus `manifest.json` against actual files and `git ls-files
release/winding-tool`. No pending manifest, stale drawing, missing file or
untracked extra was present. All 51 printable/hardware BOM rows and quantities
appear in the release guide. The safety phrase remains exact.

The reproduced reference-setting audit contains 19 passing checks, six ribs,
18 tape stations, 12 mm minimum measured tape clearance, 210 mm maximum X/Y
print envelope, 2 mm radial release, 1 mm minimum rigid brake clearance, and
14.6710599481625 mm crank-hand-envelope clearance. Its motion sample step is
30 degrees. These are recorded CAD measurements, subject to the physical
limitations below.

SHA-256 anchors, unchanged by the rebuild:

- `manifest.json`: `2cbccf041428720c8f7050e0b7cb71c7b444f2c724b605ad3e7c8d3d8b3b0fd0`
- `bom.json`: `4368d3f74f78c1afaeab27e7c5c4364c86c2f9c517817c64766bcbaa72242a23`

After the successful comparison, re-resolved and printed the deletion target:
`C:\Users\fi87roy\Documents\GitHub\windwall\.worktrees\serpentine-coil-winding-jig\build\task-8-winding-tool-backup`.
Checked exact equality to that Task 8 path, the expected worktree and its
directory prefix, and checked the rebuilt manifest still existed. Only then
ran `Remove-Item -LiteralPath $task8Backup -Recurse -Force`. The removed tree
was a verified duplicate; the rebuilt release remains and its original bytes
are recoverable from Git. `git status --short -- release/winding-tool` was empty.

## Hygiene and V5 isolation

Commands run from the worktree:

```powershell
git diff --check
git diff --check 0fbebe9 HEAD -- src tests scripts docs README.md .gitattributes ':!release/**/*.step'
git diff --check 0fbebe9 HEAD -- ':!release/**/*.step'
git diff --exit-code 0fbebe9 HEAD -- src/windwall/export.py scripts/build_v5.py release/v5
rg -n 'winding_head|wire_payoff|winding-tool' src/windwall/export.py scripts/build_v5.py release/v5/manifest.json
rg -n 'PRINT_SOURCES' src/windwall/export.py
$task8Files = @(git diff --name-only 0fbebe9 HEAD -- src tests scripts docs README.md .gitattributes)
rg -n -i 'powered.*validated.*true|physical.*verified.*true|\bTODO\b|\bFIXME\b|\bTBD\b|placeholder|NotImplemented|coming soon' -- $task8Files
rg -n -i 'powered.*validated.*true|physical.*verified.*true|\bTODO\b|\bFIXME\b|\bTBD\b|placeholder' release/winding-tool -g '*.json' -g '*.md'
```

All whitespace checks returned status 0. Claim/placeholder/coupling searches
returned no matches (the expected `rg` status 1). A separate direct
`Select-String -Pattern '[\t ]+$'` over all 19 changed source/test/doc/config
files also found no trailing whitespace. Generated STEP formatting was not
altered: its pre-existing scoped `-diff` attribute is documented by Task 7;
the explicit source/non-STEP check does not depend on that attribute.

A Python AST pass over changed Python files compared imported local names
against loaded names: `Unused-import candidates: []`, status 0. Manual review
found no dead helpers, obsolete configuration, or stale generated files.
The component modules retain small local CAD construction/validation helpers;
consolidating these would be unrelated refactoring. Bearing builders and fit
parameters remain shared with the existing bearing definitions; literal
nominal hardware selections and independent audit gauges are documented.
No dimension refactor was justified by this verification task.

The V5 exporter, builder and complete `release/v5` tree have an empty diff
against `0fbebe9`. `PRINT_SOURCES`, V5 manifest production entries and V5 STL
inventory contain the same eight names:

```text
base_rotor_module
standard_rotor_module
top_rotor_module
lower_magnet_rotor
generator_housing
coil_cassette
generator_cover
top_support
```

No winding-head or payoff member was added to that production inventory.

## Visual inspection

Opened each of the three final committed PNGs from the preserved release
backup using `view_image` with `detail: original`, at its native **2000 × 1400**
resolution. The subsequent direct byte comparison proved the rebuilt final
PNGs are precisely those inspected images.

- **Reference:** A and B have clearly separate bases and clear intervening
  space. Six orange ribs and their side tape windows are visible; central cam,
  clamp, shaft and outboard hand grip can be distinguished. Ø127, Ø150,
  Ø15 × 20 and Ø8 labels are readable. The two-608 label explains outer/inner
  ring ownership. The assembled 51105 is hidden under the platter and the
  legend explicitly refers to the exploded view. The long feed arrow points
  from B toward A and is identified as schematic. Labels and footer are not
  clipped or superimposed on other text.
- **Range:** Three distinct head states show the six ribs spreading from
  Ø110 through Ø127 to Ø145 and the changing cam position. All three panels
  have legible external numbers 1–18; contact circles and line styles agree
  with the legend. The counterclockwise arrow agrees with the German operating
  direction. Tape width, at-least-12-mm passage and 2-mm radial release are
  printed in a clear lower text block. This front view illustrates station
  alignment; tape-window depth is visible in the reference view. No label
  clipping or overlap obscures the diameter information.
- **Exploded:** Separate upper jig and lower payoff views use callouts 1–15.
  Clamp, cam, rib/slider groups, backplate, frame/shaft and crank are visually
  distinguishable. Both purple 608 envelopes sit above their upright seats.
  The lower view separates the housing washer, rolling envelope and shaft
  washer, explicitly identified as one complete 51105 with correct ownership.
  Platter/pilot and side brake group remain distinct. Some small hardware
  stays with its service group and can partially overlap in projection; this
  is a montage of service groups, not an individual-fastener assembly drawing.
  Number markers, leaders and the right-hand legend are readable and unclipped.

Each image retains the prototype/physically-unchecked footer and the exact
phrase **Akkuschrauberbetrieb ist nicht freigegeben**. No drawing change was
needed or performed.

## Documentation, limitations and handoff

Documentation updated: this report. Operator guide, assembly contract, README
and release documentation were reviewed and remain synchronized with the
verified release. No new dependency or production-part change was introduced.

CAD checks and deterministic artifact reproduction do not establish physical
fit, strength, fatigue, print support suitability, useful brake drag, enamel
protection, Ø127 calibration, electrical properties or cassette fit. Motion
checks sample 30-degree rotation and 0.5-degree cam release; they are not
continuous collision certification. Some purchased retention hardware is
specified in the BOM without detailed geometry. Physical prototypes remain
necessary. Powered operation remains unapproved.

Initial `git status --short` and the status after reproducible rebuilding were
empty. The report is in the ignored SDD directory and is explicitly staged
with `git add -f`. The measured pre-commit `git status --short` is:

```text
A  .superpowers/sdd/2026-09-15-serpentine-coil-winding-jig/task-8-report.md
```

`git diff --check` and `git diff --cached --check` both passed after staging.
The staged change contains this report alone. Commit subject:
`test: verify serpentine winding tool release`. The containing hash is obtained
without a self-referential report edit using:

```powershell
git log -1 --format=%H -- .superpowers/sdd/2026-09-15-serpentine-coil-winding-jig/task-8-report.md
git status --short
git diff --check
```

The post-commit status and hash are provided in the task handoff after those
commands run. Task 8 verification is complete; the next step belongs to the
parent's whole-branch review and integration decision.

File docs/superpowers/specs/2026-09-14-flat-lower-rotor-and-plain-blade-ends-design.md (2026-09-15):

# Flat Lower Rotor and Plain Blade Ends Design

## Purpose

Make the lower magnet rotor printable with its complete underside flat on the build plate, and simplify every stacked rotor-module blade transition by removing the separate tongue-and-groove features. The central bayonet remains the only positive rotational connection between rotor modules.

## Scope

This change affects the lower magnet rotor, all three rotor-module variants, the combined joint coupons and previews that currently contain blade tongue-and-groove geometry, their parameters and tests, and every release artifact or document that visibly or structurally depends on those parts.

The following remain unchanged:

- 18 magnets per rotor at the existing pitch circle;
- magnet diameter, pocket diameter, pocket depth and polarity convention;
- M8 threaded shaft and nut size;
- integral upper spacer sleeve on the lower magnet rotor;
- Base-module bearing labyrinth and 51105 load path;
- central bayonet dimensions, detent, direction and permanent-locking behavior;
- 70 mm nominal module height, analytic blade profile and 60-degree inter-module phase;
- stationary generator housing, coil cassette and cover geometry.

## Lower Magnet Rotor

### Flat print surface

The lower rotor keeps the existing 106 mm diameter and 5 mm magnet-carrier disc thickness. Its complete lowest exterior support surface lies on one common plane. The six radial ribs and the deeper central hub currently projecting below the disc are removed from the underside; the design must not compensate by thickening the entire carrier disc.

The central hub is rebuilt on the stator-facing upper side of the disc. It begins at the common flat carrier bottom, continues through the disc and projects upward around the spacer sleeve far enough to contain the complete 6.8 mm nut-pocket depth. Its existing 34 mm outside diameter remains inside the stationary 62 mm centre opening and therefore does not enter the active magnet or coil annulus.

The lower surface may contain the intentional M8 hexagonal nut recess and central shaft bore. These are open cavities and do not count as protrusions or prevent the surrounding annular face from lying flat on the build plate. No other solid geometry may extend below the carrier-disc bottom.

### Nut pocket and sleeve

The existing bottom-open M8 hexagonal nut pocket moves upward with the flat carrier bottom. It retains the current across-flats clearance and 6.8 mm pocket depth. The upper-side central hub surrounds the portion of the recess that extends above the 5 mm carrier disc. The pocket must remain accessible from below after printing and must not break into any magnet pocket or emerge through the top of the hub.

The 12 mm outside-diameter integral spacer sleeve remains above the magnet face and runs to the existing upper clamp-nut elevation. It retains the M8 clearance bore and remains fused to the carrier through the central disc region. Removing the lower hub must not disconnect or shorten this sleeve.

### Magnet pockets

The 18 magnet pockets remain open toward the stator-facing upper surface. Their blind floors, locations and depths remain unchanged. The flat-bottom change must preserve sufficient solid material between every pocket floor and the new print surface.

## Plain Blade Transitions

All separate blade tongue and groove solids are removed from Base, Standard and Top rotor modules. Each analytic blade wall terminates directly at its nominal lower and upper module planes. When adjacent modules are locked in their prescribed 60-degree relative phase and fully seated, corresponding blade surfaces meet flush with zero nominal axial gap.

The blade ends do not overlap and do not provide a keyed torque interface. Rotational torque between modules is transmitted only by the existing central bayonet. The blade-wall thickness and aerodynamic profile remain unchanged outside the deleted seam features.

The central end guides, local support structures and bayonet receiver/male geometry remain wherever they are needed for centering, seating and structural connection. Removing the blade seam must not remove the bayonet, create disconnected solids, reopen the shaft bore, or change the locked stage height.

## Dead-Code and Interface Cleanup

Remove the blade-seam builder, its data class, its configuration block and validation paths when no remaining production or calibration flow consumes them. Remove or revise seam-specific driver geometry, coupon assertions, preview annotations, assembly metadata, README text and manual wording.

The combined bayonet/joint coupon may retain representative plain blade-wall samples to show axial alignment, but it must not contain a tongue, groove or misleading seam-lock feature. Dedicated tongue-and-groove tests and unused seam parameters must not remain as dormant compatibility code.

## Printability

The lower magnet rotor is printed with its new flat underside on the build plate. The bottom-open nut pocket is an intentional recess; its roof is a bounded bridge and must be inspected in the slicer. The change must not require support under former ribs or hub projections.

The rotor modules retain their existing validated print orientations. Removing the small tongue-and-groove features must not introduce new unsupported lips at blade ends.

Prototype assumptions remain the Bambu Lab P2S, 0.4 mm nozzle and PLA for initial fitting. ASA remains the intended later outdoor-material trial.

## Geometry and Assembly Invariants

The implementation must prove all of the following:

1. The lower magnet rotor is one valid connected solid with a closed manifold export.
2. Its lowest solid Z equals the nominal 5 mm carrier-disc bottom across the usable annular support face.
3. No rib or hub material exists below the nominal carrier disc; the 34 mm central hub projects only toward the stator-facing upper side and remains inside the 62 mm stationary centre opening.
4. Carrier diameter and thickness remain 106 mm and 5 mm.
5. The M8 hex pocket is bottom-open at the new carrier bottom, retains its existing width and 6.8 mm depth, and remains enclosed by the upper hub while staying clear of the shaft and magnets.
6. The integral spacer sleeve retains its existing diameter, bore, upper elevation and continuous connection to the carrier.
7. All 18 magnet pockets retain their positions, dimensions, opening direction and blind floors.
8. No rotor module contains blade tongue or groove geometry.
9. Adjacent locked blade profiles meet at the common module plane with zero nominal axial gap and the prescribed 60-degree phase.
10. The bayonet remains the sole keyed torque-transfer interface and retains its current insertion, rotation, detent and locked geometry.
11. Base, Standard and Top modules each remain one valid connected solid; the complete seven-stage assembly remains collision-free.
12. The Base bearing labyrinth, generator clearances, M8 bore and top clamping interface remain unchanged.

## Testing Strategy

Development follows red-green TDD.

Lower-rotor regression tests must probe the bottom plane at representative radii and angles, reject material below that plane, verify the nut opening and pocket roof, confirm magnet floors, and verify the complete sleeve volume. A mutation or temporary legacy build with the old lower hub/ribs must fail the flatness test.

Rotor-module tests must demonstrate the absence of tongue/groove solids and verify coincident blade cross-sections at each locked Base-to-Standard, Standard-to-Standard and Standard-to-Top interface. Existing bayonet travel, detent, blade continuity, connected-solid, shaft-clearance and assembly-collision tests remain authoritative after seam-specific assertions are removed.

Export tests must confirm one closed manifold component for every changed STL. Deterministic V5 generation must refresh the lower magnet rotor, all affected rotor modules, relevant coupons and STEP assemblies, plus manifest hashes.

Documentation and canonical drawings must be regenerated when affected. All six manuals must use the same current English engineering drawings, and no text may continue to claim that blade tongues or grooves transfer torque.

## Limitations and Safety

The thinner lower-rotor structure has not been physically load-tested. Eliminating ribs reduces bending stiffness, so the printed rotor must be checked for warping and magnet-disc deflection before powered operation. The bottom-open nut pocket bridge, flat-bed adhesion and dimensional fit require slicer inspection and a prototype print.

Plain blade ends deliberately provide no secondary torque key. Every bayonet must be fully engaged and its detent verified before the rotor is spun. Outdoor, overspeed, storm, long-duration bearing protection and electrical operation remain unvalidated.

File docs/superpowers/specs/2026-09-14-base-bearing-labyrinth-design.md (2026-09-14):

# Base Bearing Labyrinth Design

## Purpose

Protect the 51105 thrust-bearing area against falling dirt and splash water without allowing the rotating Base module to contact the stationary generator cover. This prototype feature is a non-contact labyrinth, not a waterproof shaft seal.

## Scope

The change is limited to the Base rotor module and the geometry contracts and release artifacts affected by it. The generator cover, 51105 reference geometry, M8 shaft and nut interfaces, magnet pockets, blade profile, bayonet joint, and nominal magnet-carrier plate thickness remain unchanged.

## Selected Architecture

The Base receives an integral rotating cup above the magnet-carrier plate:

- The stationary generator-cover bearing boss has a 48.2 mm outside diameter (24.1 mm radius).
- The rotating cup has a 49.0 mm inside diameter (24.5 mm radius), providing 0.4 mm radial clearance per side at nominal geometry.
- The upper rotating bearing/load plate grows to 54.0 mm outside diameter (27.0 mm radius).
- The resulting cup wall is nominally 2.5 mm thick.
- The cup wall extends downward and fuses continuously to the existing magnet-carrier plate.
- The enlarged upper plate, cup wall, carrier plate, and existing blade-root reinforcement form one connected rotating solid.
- The stationary cover boss enters the cup from below and remains radially separated throughout its axial overlap.
- The existing axial clearance above the stationary boss is retained. The cup must not introduce contact with the cover, housing washer, rolling envelope, shaft washer, or cassette.

This creates a dead-end, upward-turning contamination path: debris or splash must first travel upward through the 0.4 mm annular running clearance and then turn beneath the enlarged upper plate. No rubbing lip or sacrificial contact surface is introduced.

## Printability

The Base retains its current print orientation with the large magnet-carrier plate on the build plate. The new wall grows upward from that plate. The upper closure is supported at its inner edge by the existing rotating bearing structure and at its outer edge by the new wall; the added radial bridge is small and must not require generated support material. No geometry may extend below the existing nominal carrier-plate bottom.

The prototype remains dimensioned for the Bambu Lab P2S with a 0.4 mm nozzle. The 0.4 mm running clearance is an unvalidated nominal CAD value and must be checked by hand for free rotation before powered operation, particularly with PLA and an M8 threaded rod.

## Geometry Invariants

The implementation must preserve all of the following:

1. The Base is one valid connected solid.
2. The magnet-carrier plate retains its existing diameter, thickness, elevation, and magnet pockets.
3. The blade walls remain connected to the carrier plate for torque transfer.
4. The 51105 rotating pilot, axial load shoulder, M8 bore, and nut pocket retain their existing functional dimensions and elevations.
5. The stationary generator-cover boss remains unchanged and has no intersection with the Base at nominal placement or during sampled shaft rotation.
6. The annular radial clearance between the 24.1 mm stationary radius and 24.5 mm rotating inner radius is 0.4 mm.
7. The contamination barrier is closed between the enlarged upper plate and magnet-carrier plate except for the intentional annular running opening around the stationary cover boss and the required central shaft/nut geometry.
8. The new geometry does not enter magnet pockets or the rotating/stationary keep-outs already enforced by the generator assembly.

## Implementation Boundaries

The Base construction remains owned by `src/windwall/rotor_modules.py`. Shared dimensions that are needed by both Base construction and collision tests must come from the existing generator/bearing parameter and interface functions rather than duplicated literals. A small named helper or explicit interface values may be added if that makes the clearance contract auditable.

Release generation must refresh the Base STL and STEP files, the affected generator/rotor/fence assemblies, and `release/v5/manifest.json`. Documentation images and manuals only need regeneration if their generated geometry visibly includes the modified Base; prose must continue to describe the feature as splash/dirt protection rather than waterproofing.

## Verification

Development follows a red-green test cycle. Before changing production geometry, add tests that fail against the current Base and establish:

- 0.4 mm nominal radial separation from the generator-cover boss;
- continuous material joining the 54 mm upper plate to the magnet-carrier plate around the complete circumference;
- no intersection with the stationary cover, bearing parts, magnet pockets, shaft bore, or nut pocket;
- unchanged carrier-plate bottom and nominal plate thickness;
- one valid connected Base solid and a closed manifold exported STL;
- collision-free generator assembly across the existing rotation samples.

Run the focused rotor-module and generator-housing tests first, followed by the generator, assembly, and export suites. As in the existing project, a native Windows OCP teardown status may be nonzero after `unittest` reports `OK`; the unittest result and process status must be recorded separately.

## Limitations and Safety

The labyrinth does not make the generator waterproof, does not replace drainage or an outdoor enclosure, and has not been physically validated. A 0.4 mm nominal radial gap may be insufficient if the printed parts warp or the threaded shaft runs eccentrically. Assembly must be rotated manually through a complete revolution and inspected for rubbing before installing magnets or connecting electrical loads.

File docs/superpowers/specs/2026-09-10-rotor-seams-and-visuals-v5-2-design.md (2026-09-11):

# Windwall V5.2 Rotor Seams and Visual Publishing Design

## Scope

V5.2 improves the printable base support, replaces the implicit blade tongue-and-groove construction with an explicit load-bearing seam, converts every technical drawing to English, and adds a realistic ten-rotor fence hero image plus the supplied animation. The generator architecture, seven-stage rotor height, counterclockwise wind-driven locking direction, central M8 shaft, bearing arrangement, magnet layout, and existing four-screw generator enclosure remain unchanged.

## Base support geometry

The base module shall remain one printable solid. Within the radial footprint of the large upper magnet-carrier plate, each blade root shall continue vertically down to the lowest printable plane of that plate. The continuation shall use the actual two blade footprints, not generic radial ribs. It shall support every blade-root region that would otherwise begin as an overhang when the base is printed on the plate.

The continuation must not obstruct magnet pockets, the 51105 stationary-boss clearance, the rotating bearing pilot, the captive M8 nut pocket, or the continuous shaft passage. Outside the plate footprint, the aerodynamic blade envelope remains unchanged. The result must remain a single valid, closed, manifold print body.

## Explicit blade tongue and groove

The current seam helper derives features from a broad set of horizontal faces. V5.2 shall replace that behaviour with a dedicated blade-seam builder derived only from the two aerodynamic blade cross-sections at the mating plane.

Every lower module shall expose two short upper tongues, one on each blade wall. Every upper mating module shall contain the corresponding two lower grooves. The features shall use the exact locked 60-degree phase between successive modules. Nominal PLA clearance shall be explicit in the design parameters and applied to both transverse directions without changing the external aerodynamic surface.

The seam shall satisfy all of the following:

- both blade surfaces meet without a visible axial gap in the locked pose;
- the groove fully receives the tongue without solid overlap;
- opposed tangential flanks provide positive torque contact in the counterclockwise operating direction;
- insertion and counterclockwise bayonet locking remain possible without rigid-body interference outside the intentionally elastic latch region;
- the tongue and groove do not become the only structural connection.

The permanent three-lug bayonet remains the primary module-to-module form lock. The blade seams share tangential loading and maintain aerodynamic registration. The lower captive M8 nut transfers the assembled rotor torque into the M8 shaft. The exposed upper M8 washer and nut clamp the stack axially.

## Verification and print coupons

Tests shall validate the actual solids, not metadata alone. Required checks include:

- base blade-root support down to the plate print plane;
- no support-blocking material in all protected generator, bearing, nut, and shaft volumes;
- two tongues and two grooves per applicable joint;
- correct 60-degree blade phase and zero axial seam gap in the locked pose;
- no locked-pose overlap and positive counterclockwise tangential contact;
- insertion-path sampling with the known elastic-latch limitation explicitly retained;
- single-solid validity and closed-manifold STL export;
- unchanged active blade envelope above the end-fitting region.

The joint coupon shall expose both representative blade seams as well as the bayonet interface so PLA fit can be checked before full modules are printed.

## English technical drawings

All 15 E01-E15 technical drawings shall be regenerated with English titles, labels, legends, notes, and callouts. English becomes the only tracked raster drawing language. The drawing manifest shall identify English as the raster language.

All six manuals shall embed the same English raster files. German, Chinese, Hindi, Spanish, and French manuals retain localized body text, captions, and alternative image descriptions. Documentation must no longer claim that shared drawings contain German annotations. README image references shall use only the English drawing set.

## Hero image and supplied animation

A new photorealistic, advertising-style hero image shall depict a plausible residential property with a modern house, garden, surrounding landscape, and one fence section containing approximately ten vertical Ugrinsky wind rotors. The rotors should visually correspond to the project concept while the image remains clearly presentational rather than a dimensional engineering drawing. It must not imply certification, validated output, or guaranteed outdoor safety.

The hero image shall appear near the beginning of all six manuals and at the top of the English README. Its alternative text and nearby captions shall preserve the prototype qualification.

The user-supplied `ugrinsky_windwall_10_rotors.gif` shall be copied unchanged into a tracked release media directory. The English README shall embed it directly below the hero introduction. DOCX files shall use the static hero image only; no attempt shall be made to embed or animate the GIF in Word.

## Release integration

The release shall include updated source, tests, STL and STEP exports affected by geometry, the joint coupon if its geometry changes, all affected assemblies, the 15 English drawings, the hero image, the supplied GIF, all six rebuilt manuals, audits, manifests, and release index.

Generated assets must remain reproducible where the current pipeline guarantees reproducibility. The externally generated hero image and supplied GIF shall be hash-bound in the release index but are not expected to be regenerated byte-for-byte by the CAD or drawing scripts.

## Known limits

CAD contact and clearance checks do not prove PLA strength, fatigue life, bayonet durability, real tongue-and-groove fit, rotor balance, safe speed, generator output, weather resistance, or fence structural capacity. These remain physical validation tasks. Document page rendering remains dependent on the bundled LibreOffice renderer; if it is unavailable, the release audit must state that limitation explicitly.

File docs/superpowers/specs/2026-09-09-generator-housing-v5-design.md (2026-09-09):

# Ugrinsky Wind Wall V5 – Generatorgehäuse, Lagerung und Dokumentation

## Ziel

Die bestätigten Rotorbauteile V4.3 bleiben die geometrische Basis. V5 ergänzt
einen vollständig modellierten Generatoraufbau für den späteren Einbau in einen
Holzzaun. Beide Magnetrotoren drehen mit der durchgehenden M8-Gewindestange;
Spule, Spulenkassette, Generatorgehäuse, Generator-Deckel und oberer Lagerhalter
bleiben stationär. Die Ausgabe umfasst prüfbare CAD-Modelle, STEP/STL-Dateien,
aktuelle Explosionszeichnungen und eine überarbeitete deutsche DOCX-Anleitung.

## Verbindliche Rotorbasis

- Sieben Stufen: ein Base-Modul, fünf identische Standardmodule, ein Top-Modul.
- Verriegelung gegen den Uhrzeigersinn in Winddrehrichtung.
- Dauerhafte Rastung im Bajonett; keine radialen Sicherungsschrauben.
- Geschlossene untere Kreisbahn im weiblichen Bajonett; die vertikalen
  Einführfenster enden oberhalb der Bahn.
- Flügelwand 2,0 mm; bündige, helikale Übergänge mit Nut und Feder.
- Freie Modulmitte; nur kurze M8-Führungsringe in den Endbereichen.
- Base-Flügel reichen bis in die massive obere Magnetplatte und verbinden sich
  flügelförmig mit deren zentralem Trägerring. Die früheren sechs geraden
  Radialrippen des oberen Magnetträgers entfallen.
- Base und Top erhalten lokal verstärkte Kraftbereiche für M8-Muttern.
- Die bisherige große Top-Closure entfällt.

## Rotierender Generatorstrang

Von oben nach unten:

1. Base-Modul mit integrierter oberer Magnetplatte und 18 Taschen für Magnete
   mit nominal 10 × 2 mm.
2. Rotierende Lagerscheibe des 51105, über einen gedruckten Zentrierbund mit
   knapp 25 mm Durchmesser zum Base-Modul ausgerichtet.
3. Durchgehende M8-Gewindestange.
4. Untere Magnetplatte mit 18 Magnettaschen innerhalb des Generatorgehäuses,
   unterhalb der stationären Spule.
5. Formschlüssige M8-Sechskantaufnahme in der unteren Magnetplatte.

Die untere Magnetplatte muss innerhalb des geschlossenen Gehäuseraums rotieren.
Sie darf weder Spulenkassette noch Gehäuseboden, Seitenwand, Deckel oder
Schraubkanäle berühren. Magnetpolarität und Luftspalte bleiben in den
Explosionszeichnungen eindeutig bezeichnet.

## Unteres Axiallager 51105

Das vorgesehene einseitig wirkende Axialkugellager 51105 hat die normativen
Hauptabmessungen 25 × 42 × 11 mm. Die Konstruktion verwendet zunächst folgende
PLA-Prototypmaße:

- stationärer Außensitz: 42,2 mm;
- Gesamttiefe des Einbauraums: 11,2 mm;
- rotierender Zentrierbund: nominal knapp unter 25 mm;
- zentrale Durchführung für die M8-Welle und ihre Mutteraufnahme.

Die stationäre Lagerscheibe stützt sich auf einem zentralen Bund des
Generator-Deckels ab. Die rotierende Lagerscheibe wird durch den Zentrierbund
des Base-Moduls geführt. Das Lager übernimmt die axiale Rotorlast. Ein
dreistufiger Passungscoupon muss vor einer Druckfreigabe unterschiedliche
Sitzmaße um das Nominalmaß prüfen. Die Maße sind nicht als Presspassung
freigegeben, bevor Lager und Coupon real vermessen wurden.

## Stationäres Generatorgehäuse

Der erste Entwurf ist ein von oben montierbarer Topf:

- ungefähr 130 mm Gehäuse-Außendurchmesser;
- mindestens 120 mm nutzbarer Innenraum;
- geschlossener Boden mit ausreichendem Abstand zur unteren Magnetplatte und
  deren M8-Hardware;
- vier gleichmäßig verteilte äußere Bodenlaschen zur Verschraubung nach unten
  auf einen Holzrahmen;
- verstärkter seitlicher Kabelausgang als Prototyp, ausdrücklich noch nicht
  wasserdicht;
- symmetrische Grundarchitektur, damit später eine umgedrehte oder abgedichtete
  Variante konstruiert werden kann.

Die Befestigungslaschen dürfen den rotierenden Innenraum nicht einschränken.
Ihre Holzschrauben liegen außerhalb aller Magnet- und Spulenbereiche.

## Spulenkassette

Die Serpentinen-Spule sitzt in einer separaten, austauschbaren stationären
Kassette mit ungefähr 118 mm Außendurchmesser. Sie wird:

- nach unten durch eine umlaufende Gehäuseschulter getragen;
- radial durch einen Passring mit zunächst 0,3–0,4 mm Druckspiel zentriert;
- durch eine eindeutige Nase/Tasche gegen Verdrehung gesichert;
- durch den verschraubten Deckel axial nach oben gehalten;
- nach Abnahme des Deckels nach oben entnommen;
- seitlich mit Zugentlastungsmöglichkeit aus dem Gehäuse geführt.

Ein eigener Passungscoupon prüft die radiale Kassettenschnittstelle. Die
Spulenwicklung bleibt als experimentelle 20/40/80-Windungs-Matrix für jeden
gemessenen Drahtdurchmesser dokumentiert; es wird keine endgültige Wicklungszahl
behauptet.

## Generator-Deckel

Der stationäre Deckel erfüllt vier Aufgaben:

1. Spulenkassette axial sichern;
2. zentralen stationären Sitz des 51105 tragen;
3. den oberen Magnetrotor mit definiertem Luftspalt von der Spule trennen;
4. den Gehäusetopf verschließen.

Sechs gleichmäßig verteilte M4-Durchgangsschrauben und gefangene
M4-Sechskantmuttern verbinden Deckel und Topf. Gedruckte Gewinde werden im
PLA-Prototyp vermieden. Der Deckel darf nicht mitrotieren.

## Luftspalte und Einbaureihenfolge

Die ersten CAD-Nennwerte betragen oben und unten jeweils 1,5 mm von der
Magnetfläche zur aktiven Wicklungsfläche. Beide magnetischen Abstände enthalten
den dazwischenliegenden Kunststoff: oben die 1,00 mm dicke Deckelmembran,
unten den 1,00 mm dicken Kassettenboden. Sie gelten nur für bündig oder tiefer
sitzende Magnete. Die mechanischen Freigänge betragen oben 0,35 mm zwischen
Magnetfläche und Deckelmembran und unten 0,50 mm zwischen Magnetfläche und
Kassettenboden. Weitere 0,15 mm zwischen Kassettenoberkante und Deckelunterseite
erlauben die axiale Rückhaltung. Diese Bezugsebenen sind die verbindliche,
im Abschlussreview bestätigte Interpretation; die Nenngeometrie bleibt unverändert.
Die Einbaureihenfolge ist:

1. untere Magnetplatte und M8-Hardware in den Gehäusetopf einsetzen;
2. Spulenkassette auf Schulter und Verdrehsicherung setzen;
3. stationären Deckel montieren;
4. 51105 auf stationären und rotierenden Zentrierflächen einsetzen;
5. Base-Rotor und restlichen Rotorstapel montieren.

Ein Kollisionsaudit prüft jeden rotierenden Körper gegen alle stationären
Körper. Vorgesehene Lagerkontakte werden separat benannt; alle anderen
Überschneidungen müssen unter der numerischen Toleranz liegen.

## Oberer stationärer Lagerhalter

Der obere Lagerhalter wird neu konstruiert und verwendet keine
Original-Befestigungspunkte:

- rechteckige Platte, zunächst 80 × 50 × 12 mm;
- 608-Lager, 8 × 22 × 7 mm;
- von oben zugänglicher Prototypsitz 22,2 × 7,2 mm;
- geschlossene untere Schulter von ungefähr 3 mm;
- zentrale M8-Durchführung;
- vier symmetrische, von unten zugängliche versenkte Bohrungen für ungefähr
  4 × 40 mm Holzschrauben;
- Befestigung von unten gegen einen vorhandenen oberen Holzrahmen;
- der Holzrahmen verschließt den Lagersitz oben und hält das Lager gefangen.

Der 608-Lagerpunkt führt hauptsächlich radial. Das 51105 trägt die Axiallast.
Eine lokal abgeschliffene M8-Gewindestange ist zulässig; eine gedruckte
Führungshülse gehört nicht zum Entwurf. Zwischen rotierendem Top-Modul und
stationärem Lagerhalter bleibt ein definierter Sicherheitsabstand.

## Aerodynamischer oberer Abschluss

Der Ugrinsky-Rotor muss für diese Konstruktionsstufe nicht durch eine große
rotierende Scheibe geschlossen werden. Das Top-Modul behält nur den lokal
verstärkten M8-Kraftbereich. Eine optionale aerodynamische Endscheibe kann
später vergleichend getestet werden, gehört aber nicht zu V5.

## Passungsproben

V5 erzeugt mindestens:

- 51105-Außensitz-Coupon mit drei Durchmessern;
- 25-mm-Zentrierbund-Coupon;
- 608-Sitz-Coupon mit drei Durchmessern;
- Spulenkassetten-Passungssegment;
- bestehenden Magnettaschen-Coupon;
- bestehenden männlichen/weiblichen Bajonett-Rastcoupon.

Jeder Coupon wird als eigenes STL ausgegeben und mit den verwendeten Maßen in
einem Manifest dokumentiert.

## Explosionszeichnungen

Aktuelle Zeichnungen zeigen mindestens:

- vollständigen siebenstufigen Rotor;
- alle drei Rotormodultypen und ihre Übergänge;
- Base-Modul, 51105 und Generator-Deckel im Schnitt;
- vollständigen Generator mit oberer Magnetplatte, Spule und unterer
  Magnetplatte innerhalb des Gehäuses;
- stationäre und rotierende Teile durch Farbe und Legende getrennt;
- untere Gehäusebefestigungslaschen und seitlichen Kabelausgang;
- oberen 608-Lagerhalter und die Montage von unten am Holzrahmen;
- vollständige Gesamtmontage zwischen unterem und oberem Zaunrahmen.

Keine Zeichnung darf Generatorgehäuse oder Spule als rotierend darstellen.

## DOCX-Anleitung

Die vorhandene deutsche Anleitung wird neu erzeugt und enthält:

- aktuelle V4.3/V5-Teileliste und Dateinamen;
- Druckhinweise für PLA-Test und später ASA;
- Montage des Generators in korrekter Reihenfolge;
- Einbauorientierung von 51105 und 608;
- Kennzeichnung stationärer/rotierender Komponenten;
- Magnetpolung und beide Luftspalte;
- Spulenkassetten-Sicherung und seitliche Kabelführung;
- Serpentinen-Testmatrix für gemessene Drahtdurchmesser;
- Warnung vor direktem Anschluss an den 48-V-Bleiakku;
- bekannte Grenzen: keine Wasserdichtheit, keine freigegebenen Presspassungen,
  keine abschließend bestimmte Wicklung und keine physische Dauerfestigkeit.

Die DOCX wird strukturell und barrierearm geprüft. Eine visuelle Seitenprüfung
und PDF-Ausgabe erfolgen nur, wenn ein geeigneter LibreOffice-Renderer
verfügbar ist; fehlende Renderprüfung darf nicht als bestanden bezeichnet
werden.

## Ausgaben

Die stabile Release-Ausgabe enthält:

- STEP und STL aller aktuellen Druckteile;
- STEP der verriegelten Rotor- und Generatorbaugruppen;
- Coupon-STLs und Maßmanifest;
- Explosionszeichnungen als hochauflösende PNGs;
- aktuelle deutsche DOCX-Anleitung;
- maschinenlesbares Release-Manifest mit Abmessungen, Stückzahlen und
  Validierungsstatus.

Veraltete Top-Closure-Ausgaben werden entfernt oder ausdrücklich als obsolet
markiert. Die generierten Dateien bleiben reproduzierbare Build-Artefakte.

## Prüfung und Freigabegrenzen

Automatisierte Prüfungen decken mindestens ab:

- gültige, zusammenhängende Druckkörper;
- Lager- und Couponmaße;
- freie M8-Wellenpassage;
- Position der unteren Magnetplatte innerhalb des Gehäuses;
- Stillstand aller Gehäuse-/Spulenteile;
- Luftspalte und Kollisionsfreiheit;
- Sicherung der Spulenkassette in allen Freiheitsrichtungen;
- Befestigungszugang für Deckel, Bodenlaschen und oberen Lagerhalter;
- Vollständigkeit von Exportmanifest, Zeichnungen und DOCX.

Automatisierte Geometrieprüfungen ersetzen keine reale Passungs-, Magnet-,
Wicklungs-, Belastungs-, Schwingungs-, Wetter- oder Sicherheitsprüfung. Der
erste Release bleibt ein PLA-Passungsprototyp.

## Versionskontrolle und Veröffentlichung

Der bestehende Rotorstand ist durch Commit `cdd1c2d` gesichert. Die V5-Arbeit
erhält nach bestandenen fokussierten Prüfungen einen weiteren Commit. Nach
abschließender Prüfung werden Quellcode, Tests, Dokumentation und die vereinbarte
Release-Struktur zum konfigurierten GitHub-Remote `origin` gepusht. Ein Push
erfolgt erst, wenn die erzeugten Dateien und bekannten Einschränkungen im
Abschlussbericht genannt sind.

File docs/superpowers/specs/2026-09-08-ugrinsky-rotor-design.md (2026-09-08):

# Parametric Ugrinsky Wind Wall Rotor Design

## Purpose

This project reconstructs the supplied Ugrinsky wind wall STL models as clean,
parametric CAD geometry. The first deliverable is a seven-stage rotor stack with
a wind-tightening bayonet interface, a continuous M8 threaded rod, and the
original dual-rotor axial-flux generator arrangement.

The design preserves the original Ugrinsky blade geometry as closely as
practical. Local changes are limited to structurally necessary hubs, blade-end
drivers, bayonet features, fastener access, and the top closure.

## Reference Geometry

The following supplied files are measurement references only and will not be
used as production solids:

- `1 Base.stl`
- `2 Coil_Former.stl`
- `3 magnet_ring (2).stl`
- `4 Stator_Cover_PLate.stl`
- `5 Top_Bearing.stl`
- `6 Ugrinsky_Base.stl`
- `7 Ugrinsky_Blade.stl`

Initial mesh inspection found the generator base parts mostly closed and
manifold. `5 Top_Bearing.stl`, `6 Ugrinsky_Base.stl`, and especially
`7 Ugrinsky_Blade.stl` contain non-manifold topology. The blade STL also
contains four disconnected components and degenerate faces. Production parts
will therefore be reconstructed rather than repaired through mesh booleans.

## Coordinate and Rotation Convention

- The rotor axis is the global Z axis.
- Positive Z points upward from the generator toward the top module.
- Rotation is viewed from above, looking down along negative Z.
- Normal wind-driven rotation is counterclockwise in this view.
- Every bayonet ramp and end stop shall be oriented so counterclockwise rotor
  torque drives the joint toward its locked end position.

## Rotor Stack

The nominal stack contains seven aerodynamically active stages and is about
490 mm high:

1. One base rotor module with the upper magnet rotor integrated into its lower
   structure.
2. Five identical standard rotor modules.
3. One top rotor module with a reinforced washer-bearing hub and exposed M8 clamp nut.
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

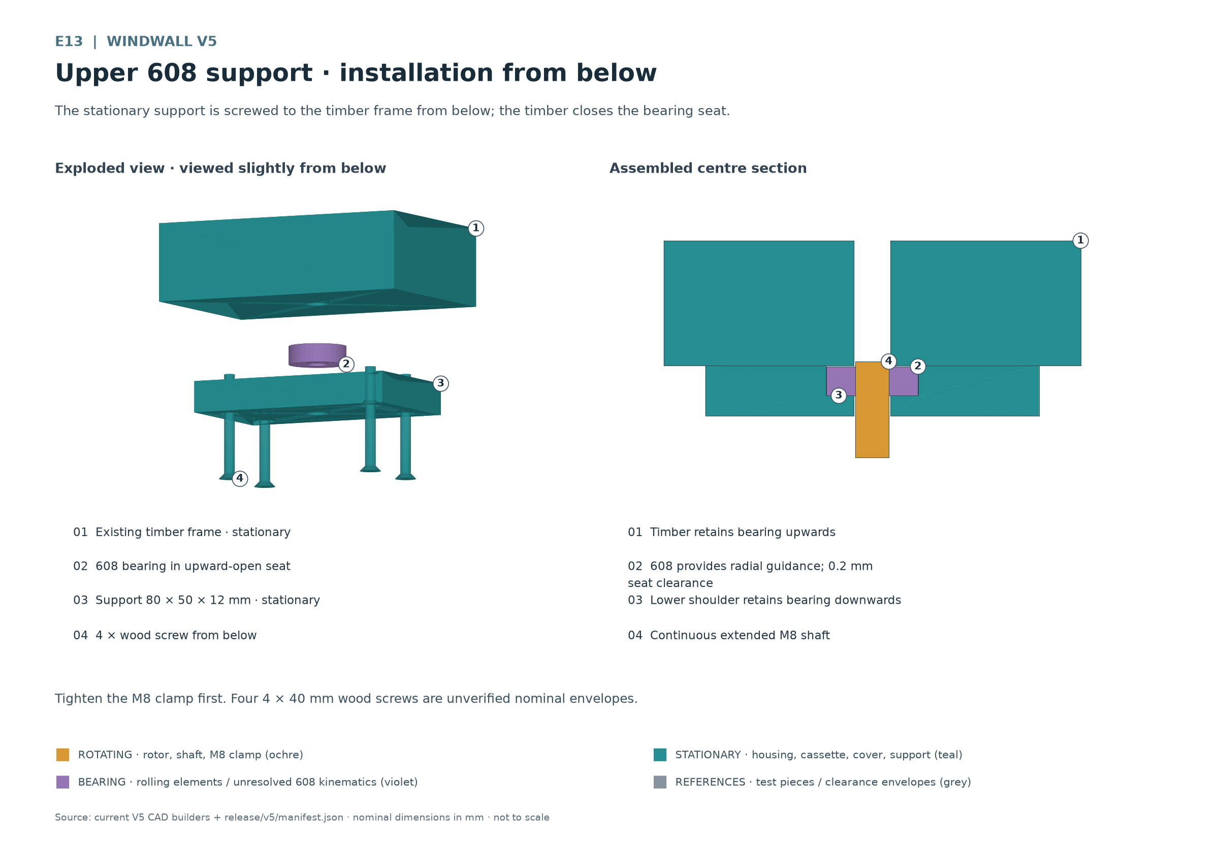
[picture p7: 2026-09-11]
release/v5/drawings/E13-oberer-halter.png

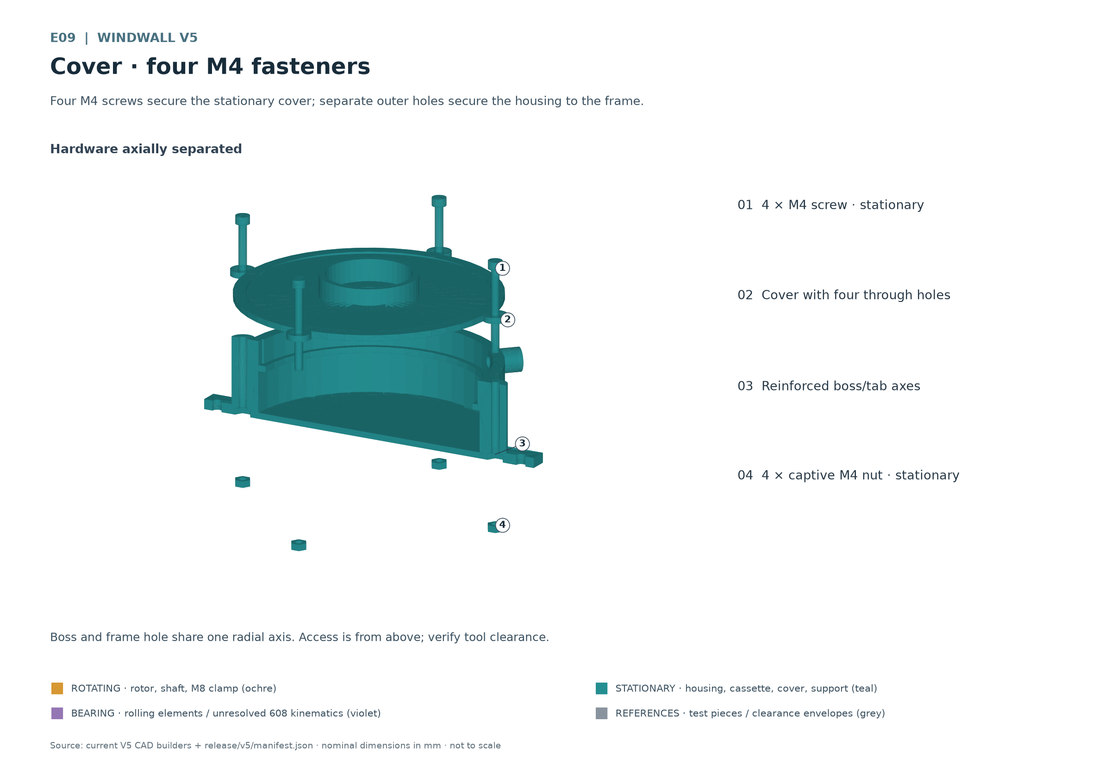
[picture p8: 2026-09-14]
release/v5/drawings/E09-deckelverschraubung.png

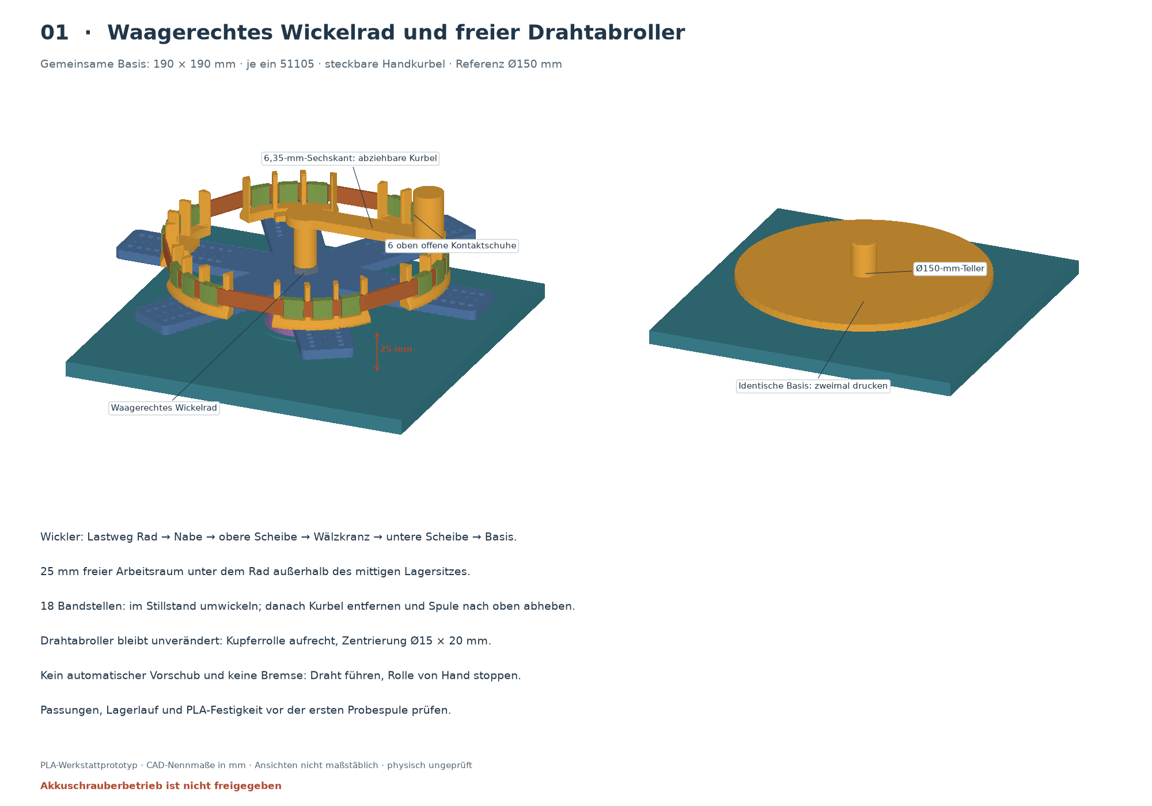
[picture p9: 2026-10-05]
release/winding-tool/drawings/winding-jig-reference.png

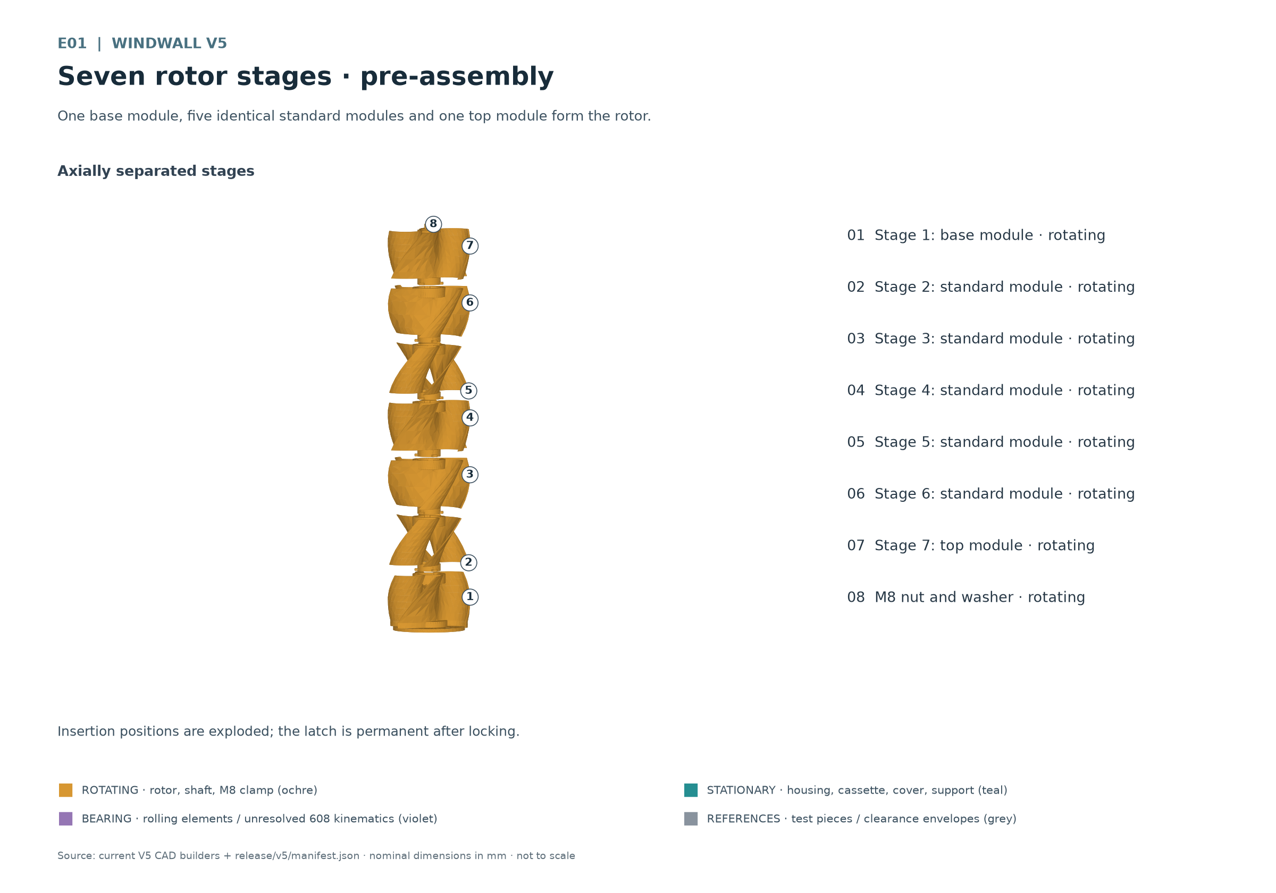
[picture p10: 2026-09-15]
release/v5/drawings/E01-rotorstapel.png

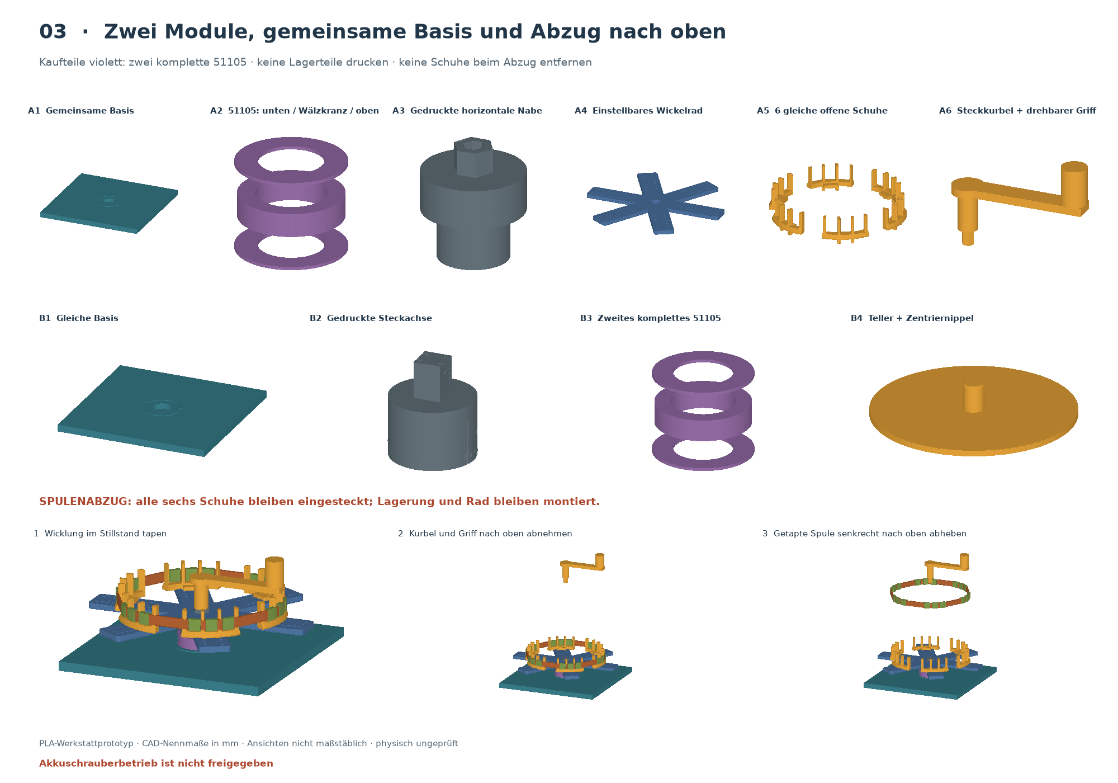
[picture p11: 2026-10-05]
release/winding-tool/drawings/winding-tool-exploded.png

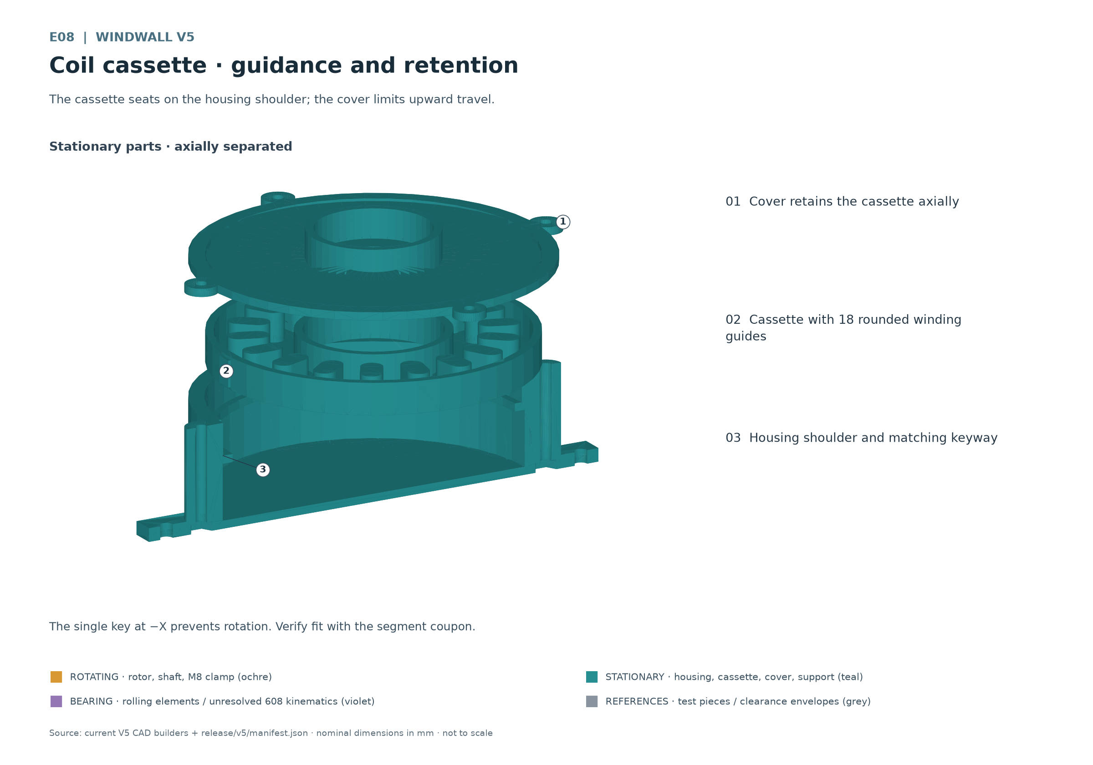
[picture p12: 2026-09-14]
release/v5/drawings/E08-kassettenrueckhaltung.png

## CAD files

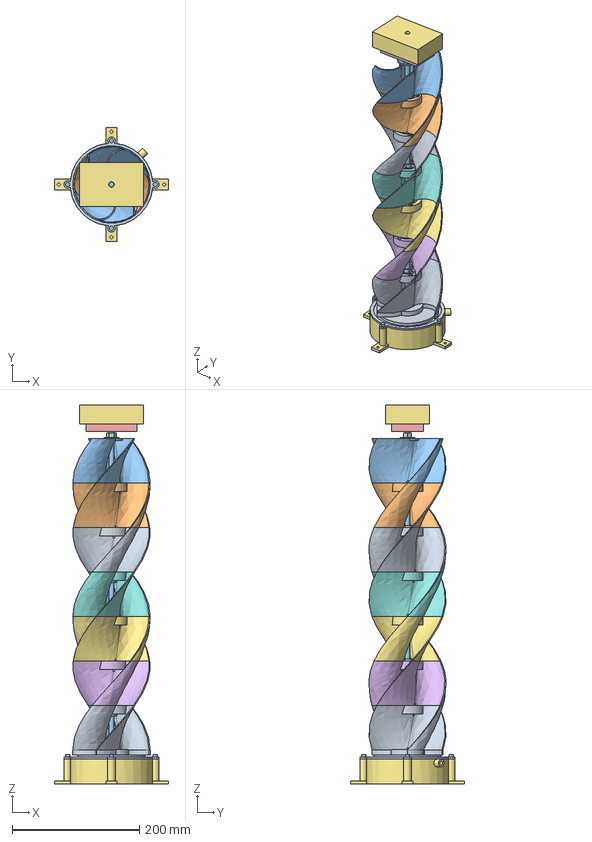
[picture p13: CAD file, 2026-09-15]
release/v5/assembly/fence_assembly.step
180.0 x 180.0 x 596.3 mm
base
lower_magnet_rotor
shaft
upper_nut
lower_nut
upper_magnets
lower_magnets
51105_shaft_washer
housing
coil_cassette
cover
winding_volume
51105_housing_washer
cover_screw_1
cover_nut_1
cover_screw_2
cover_nut_2
cover_screw_3
cover_nut_3
cover_screw_4
cover_nut_4
51105_rolling_envelope
standard_1
standard_2
standard_3
standard_4
standard_5
top
top_washer
top_nut
top_support
bearing_608
upper_wood_frame_reference
wood_screw_1_reference
wood_screw_2_reference
wood_screw_3_reference
wood_screw_4_reference

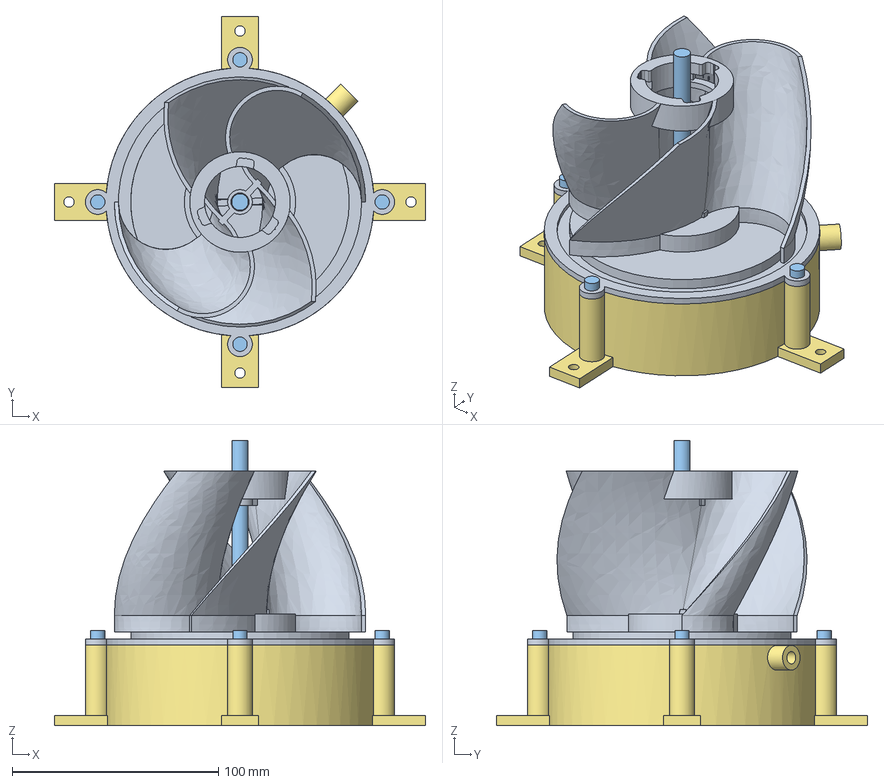
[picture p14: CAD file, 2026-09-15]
release/v5/assembly/generator.step
180.0 x 180.0 x 138.5 mm
base
lower_magnet_rotor
shaft
upper_nut
lower_nut
upper_magnets
lower_magnets
51105_shaft_washer
housing
coil_cassette
cover
winding_volume
51105_housing_washer
cover_screw_1
cover_nut_1
cover_screw_2
cover_nut_2
cover_screw_3
cover_nut_3
cover_screw_4
cover_nut_4
51105_rolling_envelope

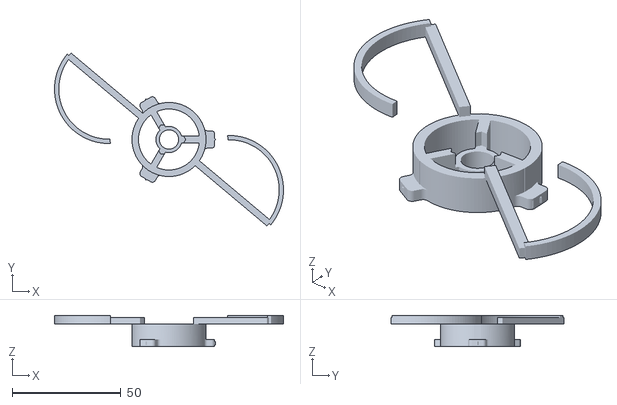
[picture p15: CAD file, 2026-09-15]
release/v5/coupons/joint_male.stl
105.2 x 79.4 x 14.4

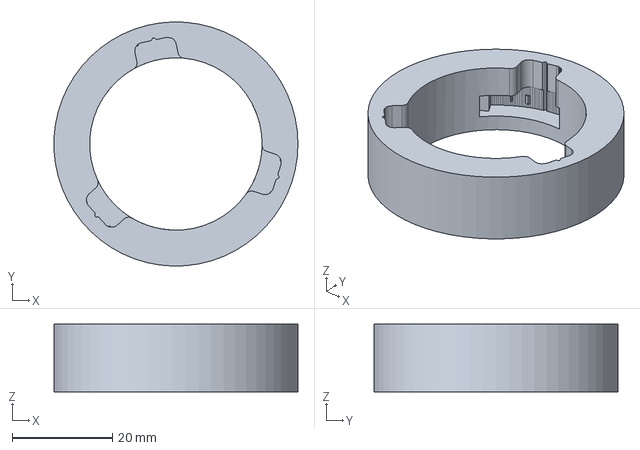
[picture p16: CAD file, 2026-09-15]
release/v5/step/bayonet_female.step
48.7 x 48.7 x 13.6 mm

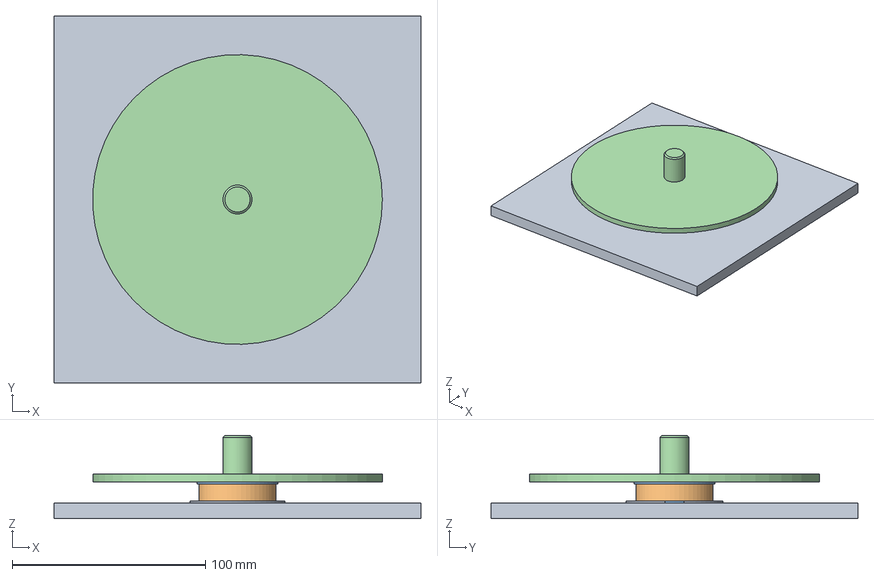
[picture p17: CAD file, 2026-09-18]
release/winding-tool/assembly/free_running_wire_payoff.step
190.0 x 190.0 x 43.0 mm
base
bearing
lower_washer
platter
spindle
upper_washer

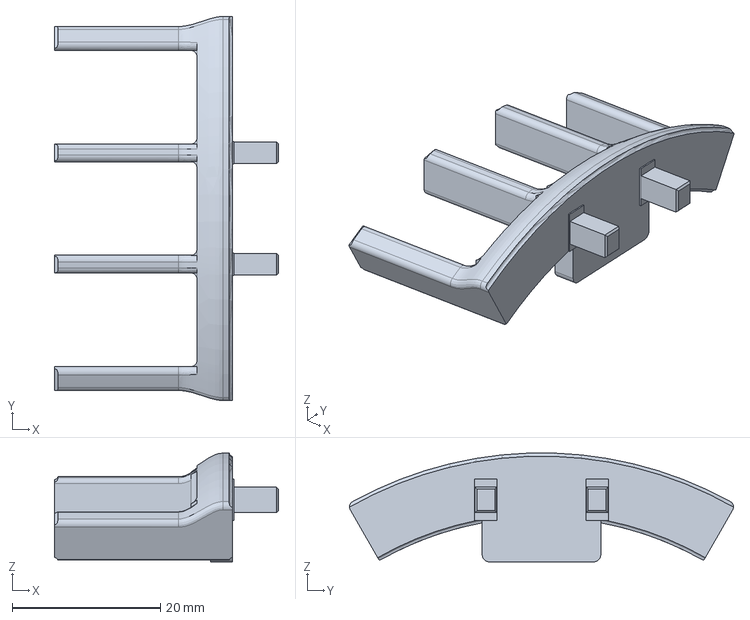
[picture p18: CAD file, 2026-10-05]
release/winding-tool/step/winding_jig_contact_shoe.step
30.2 x 51.8 x 14.7 mm

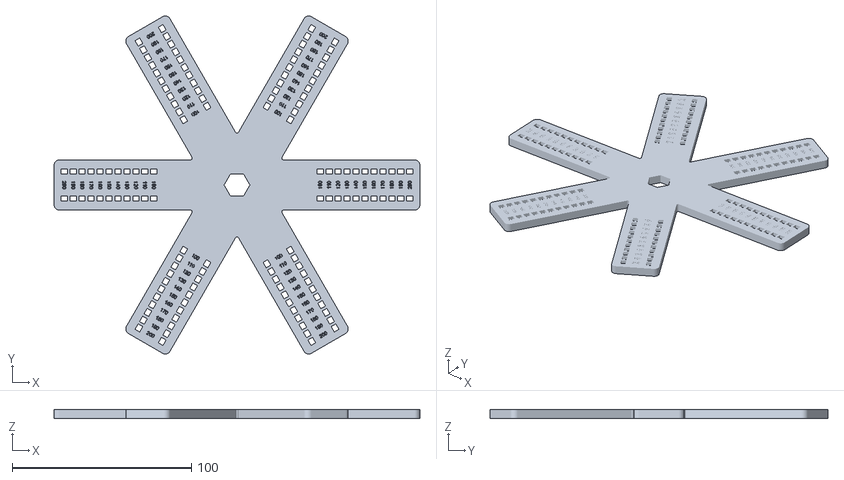
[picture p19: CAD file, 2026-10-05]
release/winding-tool/stl/winding_jig_coil_wheel.stl
204.0 x 188.5 x 5.00

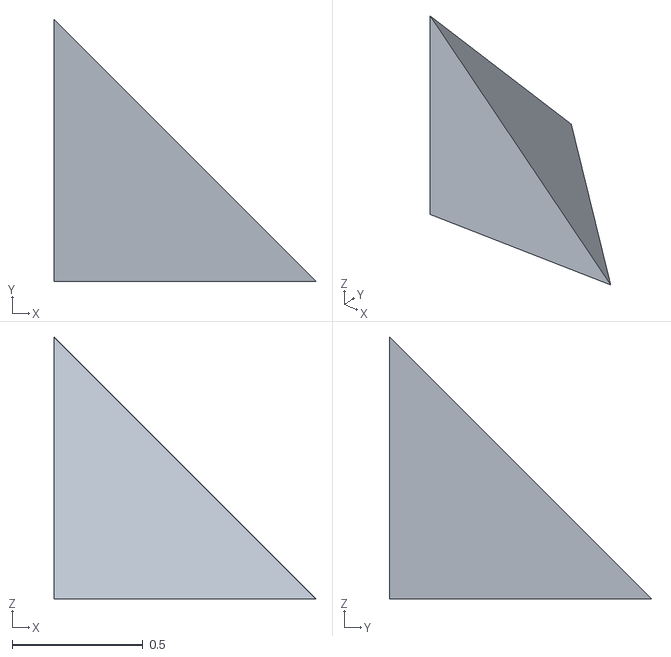
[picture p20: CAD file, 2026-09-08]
tests/fixtures/tetrahedron_binary.stl
1.00 x 1.00 x 1.00

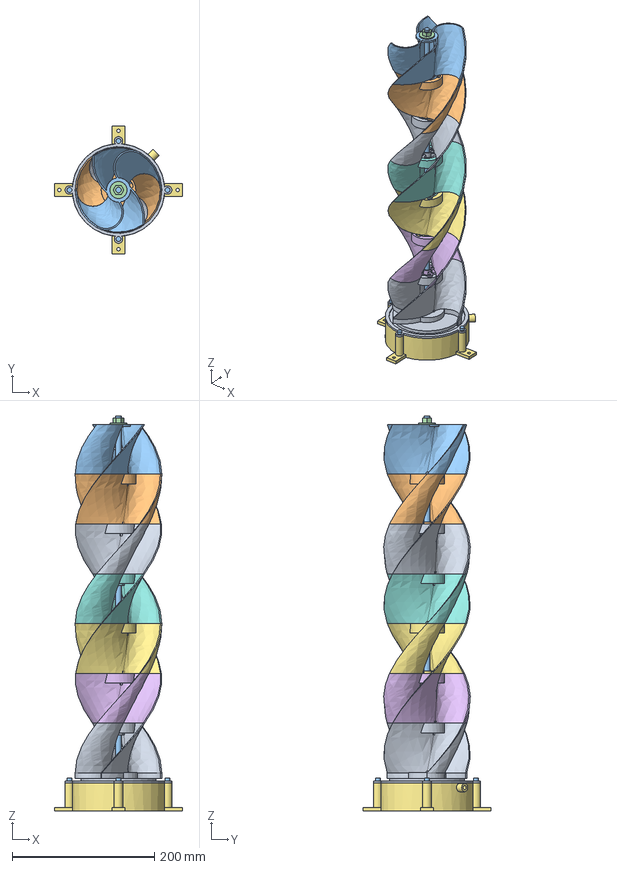
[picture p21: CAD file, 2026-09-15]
release/v5/assembly/rotor_locked.step
180.0 x 180.0 x 555.3 mm
base
lower_magnet_rotor
shaft
upper_nut
lower_nut
upper_magnets
lower_magnets
51105_shaft_washer
housing
coil_cassette
cover
winding_volume
51105_housing_washer
cover_screw_1
cover_nut_1
cover_screw_2
cover_nut_2
cover_screw_3
cover_nut_3
cover_screw_4
cover_nut_4
51105_rolling_envelope
standard_1
standard_2
standard_3
standard_4
standard_5
top
top_washer
top_nut

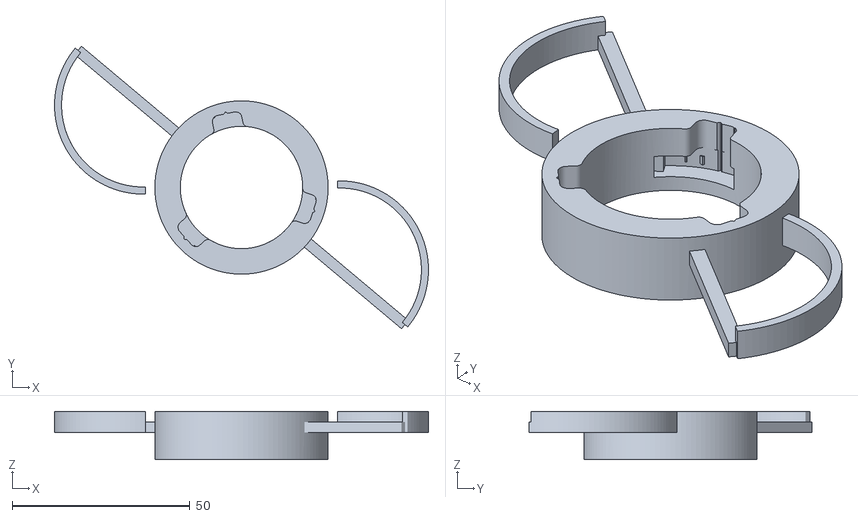
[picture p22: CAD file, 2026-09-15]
release/v5/coupons/joint_female.stl
105.2 x 79.4 x 13.6

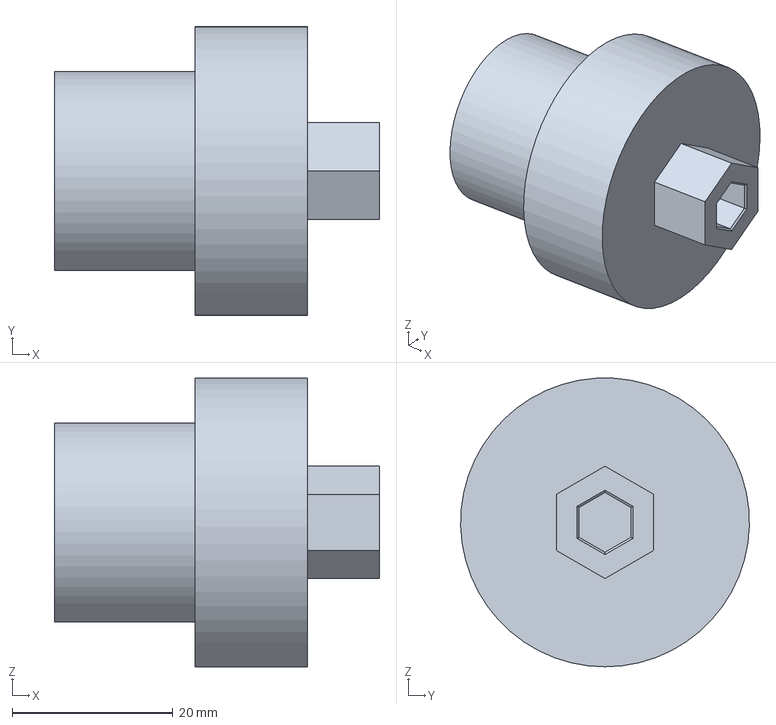
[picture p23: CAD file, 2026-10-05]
release/winding-tool/step/winding_jig_horizontal_hub.step
40.5 x 36.0 x 36.0 mm

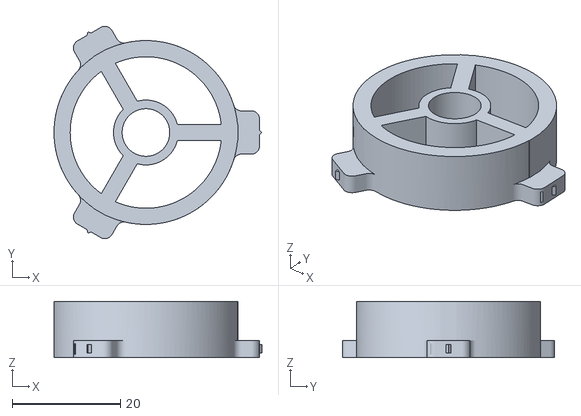
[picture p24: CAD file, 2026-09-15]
release/v5/coupons/bayonet_male.stl
38.5 x 39.3 x 10.4

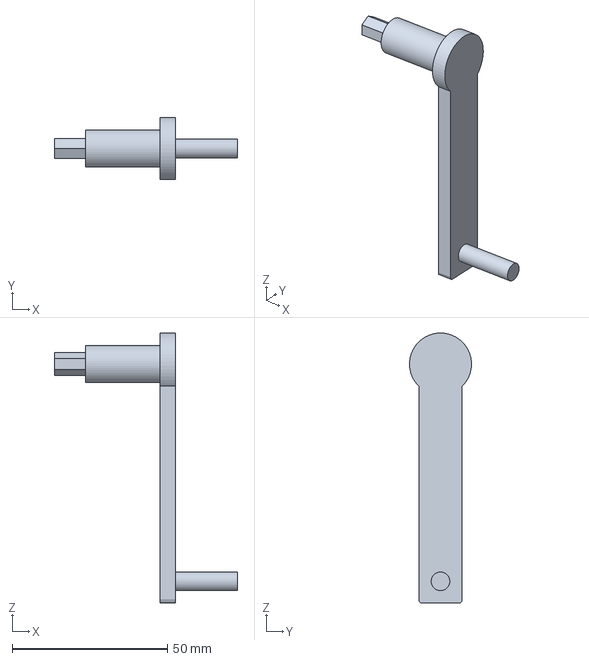
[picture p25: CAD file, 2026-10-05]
release/winding-tool/step/winding_jig_hand_crank.step
59.0 x 20.0 x 87.0 mm

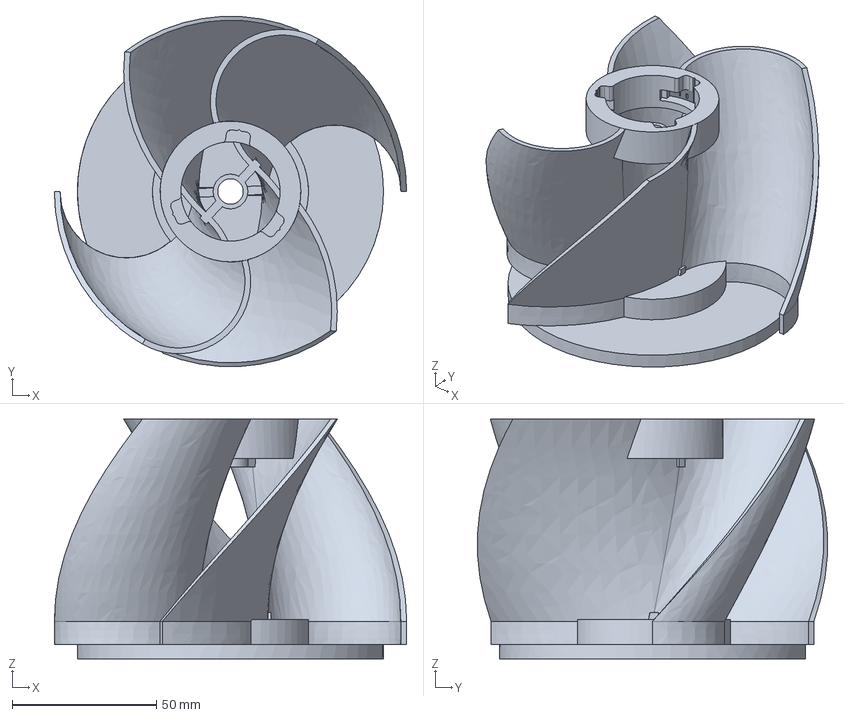
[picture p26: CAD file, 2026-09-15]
release/v5/step/base_rotor_module.step
122.0 x 121.2 x 83.0 mm

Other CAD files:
release/v5/step/joint_female.step
release/v5/step/joint_male.step
release/v5/coupons/bayonet_female.stl
release/winding-tool/step/winding_jig_rotating_grip.step
release/v5/coupons/25mm_pilot_coupon.stl
release/v5/coupons/51105_outer_seat_coupon.stl
release/v5/coupons/608_seat_coupon.stl
release/v5/coupons/coil_cassette_segment_coupon.stl
release/v5/coupons/magnet_pocket_coupon.stl
release/v5/step/25mm_pilot_coupon.step
release/v5/step/51105_outer_seat_coupon.step
release/v5/step/608_seat_coupon.step
release/v5/step/bayonet_male.step
release/v5/step/coil_cassette.step
release/v5/step/coil_cassette_segment_coupon.step
release/v5/step/generator_cover.step
release/v5/step/generator_housing.step
release/v5/step/lower_magnet_rotor.step
release/v5/step/magnet_pocket_coupon.step
release/v5/step/standard_rotor_module.step
release/v5/step/top_rotor_module.step
release/v5/step/top_support.step
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

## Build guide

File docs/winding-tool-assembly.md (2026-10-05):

# Horizontal manual winding-tool assembly

The PLA prototype consists of two independent manual modules: a horizontal coil
wheel and an upright-wire-roll payoff turntable. Both use the unchanged
190 × 190 mm payoff base and one complete purchased 51105 (25 × 42 × 11 mm).
For simultaneous operation print the common base twice and buy two bearings.
The BOM contains 14 printed occurrences from eight masters; bearing washers and
rolling members are purchased components, not printed races.

See the [German operating guide](serpentine-coil-winding-tool-de.md) for the
canonical BOM, print orientations, tape-angle table and operating precautions.
The [horizontal design](superpowers/specs/2026-09-26-horizontal-coil-winder-design.md)
defines the intended arrangement.

## Winder assembly and operation

1. Put the lower 51105 washer, rolling member and upper washer in the base seat.
2. Insert the horizontal hub through the bearing and base bores. Its guide ends
   at bench Z=1.5 mm, above the 1 mm blind floor. The upper washer carries weight;
   the long clearance pilot supplies radial guidance.
3. Seat the existing wheel on the 14 mm circumdiameter polygon. The flat stop
   sets its underside to Z=33 mm: 25 mm above the base surface outside its boss.
4. Fit all six shoes at the same marked setting, 100–200 mm in 10 mm increments.
   The two 3.40 × 2.90 mm rigid tongues enter 3.50 × 3.00 mm openings with
   0.05 mm nominal clearance per side. Their wider rails form positive stops.
5. Insert the removable top crank and fit its freely rotating printed grip.
   The male hex is 6.35 mm across flats; the female socket is 6.45 mm across flats.
   There is no latch or drive screw. The raised arm clears the shoe tops.
6. Turn slowly by hand, guide the wire and stop the independent payoff by hand.
7. Stop rotation and close all 18 tape wraps through the three channels per shoe.
   Each channel reserves at least 12 mm tangential and axial clearance for 10 mm tape.
8. Remove the crank and grip upward. Lift the taped coil vertically over all six
   still-seated shoes; do not move the shoes inward or unplug them for release.

The shoes retain a rounded 2.7 mm lower support but have zero upper radial
projection. Tape channels open upward, with no crossbar trapping closed loops.
The actual winding is a rounded six-sided envelope, not a calibrated circle.

## Unchanged wire payoff

Use the second common base and second 51105. Retain the payoff's printed spindle,
square platter plug and existing removable detents. The Ø150 mm platter's
Ø15 × 20 mm integral nipple centers the upright supply roll. The platter and
spindle are not mechanically linked to the crank.

For payoff service lift the platter, then the spindle, then the bearing members.
The existing ramps and flexible tongues release the two payoff plugs. Their fit,
elastic behavior and life still need physical verification. The upper plug hangs
the spindle before its guide reaches the blind floor. The payoff geometry,
service checks and common-base STL/STEP bytes are unchanged by this redesign.

## Print and prototype limits

The STL masters are already oriented and translated to minimum Z=0. Print the
base and wheel flat; the shoes rotated −90° about Y onto their flat inward foot
face; the hub and crank rotated
90° about Y; the grip upright. The payoff spindle also lies horizontally.
Use support where required, keeping fits and tape passages clean. All masters
fit a 220 × 220 mm bed. First test a shoe and the drive/bearing fits, deburr
carefully and inspect the first coil for enamel damage.

The loose plug crank and removable grip have no positive transport retention.
Remove them before carrying the tool. Gravity seats the wheel and hub; there is
no fragile snap keeping the horizontal winder assembled. Secure the common base
on its clamp lands if real wire tension causes sliding or tipping.

Wear eye protection. Keep hair, clothing, fingers, tape and loose wire clear.
Inspect for cracks, whitening, looseness and rough wire-contact edges before use.
Stop on abnormal resistance. PLA strength, wear, creep, bearing life, winding
accuracy, stability, enamel protection and release force remain unvalidated.
The bit socket is a future interface, not motor-operation approval:
Akkuschrauberbetrieb ist nicht freigegeben.

## CAD interfaces and release gates

`WindingToolAssemblies` owns two tool dictionaries, occurrence ownership,
parameters and audit results. Both tools use independent bench origins with
vertical Z axes. Head installation is translation-only at `wheel_bottom_z_mm`.
Recover local head coordinates by subtracting that translation, without rotation.

Each occurrence has a source and motion role. Printed occurrences also have a
global `canonical_master` identity and documented print rotations. Both bases
use `wire_payoff/base`. Each module has its own bearing `purchase_set`; the
three physical 51105 members count as one complete purchased set per module.
Mutations replace immutable Workplanes rather than editing cached shapes.
The legacy `release_clearance_mm` parameter is retained for caller compatibility,
but is ignored by horizontal release: shoes do not move radially.

The assembly audit verifies actual solids rather than trusting `model.audit`.
It repositions the actual shoes through all eleven settings, preserving defects.
Continuous full-revolution envelopes must contain the real parts and clear
stationary material. Axial sections preserve narrow hub/spindle guide journals.
The winder load path, pilot floor clearance, polygon torque engagement, working
gap, complete canonical bearing poses, tape corridors and base identity are gates.

`coil_removal_stages` retains all occurrences in three poses: held winding,
upward crank/grip removal and upward taped-coil removal. The service audit checks
ownership, fixed-member continuity and every swept boundary face, not just motion
endpoints. All six shoes stay fixed throughout. The fixture is bounded to a
9 mm axial winding with 1 mm radial build and eighteen closed tape loops having
10 mm tangential width, 10 mm axial height, 4 mm radial span and 0.25 mm walls.
It follows the curved contact arcs and taut spans between them. Its height is
found by descending the actual reference coil to the rounded lower support;
the production audit separately requires contact within a 0.02 mm downward
probe at all six actual shoes. The closed tape and upward sweep use that same
gravity-seated pose, not a floating nominal height.

The schema-3 manifest records all `assembly_occurrences` of each global master,
including the shared base across both tools. Export rejects conflicting grouped
geometry, malformed ownership, incorrect quantities or failed audits. It checks
single solids, closed manifold meshes, STL bed orientation, STEP reimports and
all artifact hashes before publishing success. Drawings consume current CAD;
guide tables consume the same BOM. V5 geometry and its `PRINT_SOURCES` are unchanged.

`physical_validation_verified`, `powered_operation` and `print_ready` remain
false: the files are geometrically checked prototype candidates, not physical
production or motor-operation approval.

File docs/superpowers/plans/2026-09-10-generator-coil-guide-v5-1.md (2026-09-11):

# Generator Coil Guide V5.1 Implementation Plan

> **For agentic workers:** REQUIRED SUB-SKILL: Use superpowers:subagent-driven-development (recommended) or superpowers:executing-plans to implement this plan task-by-task. Steps use checkbox (`- [ ]`) syntax for tracking.

**Goal:** Add an original-style open serpentine winding guide, four aligned M4 cover bosses, and an integral lower-rotor spacer sleeve.

**Architecture:** `generator_housing.py` owns all stationary winding-guide and fastener geometry. `generator.py` owns the fused rotating sleeve and assembly motion classification. Existing export, drawing and manual builders consume these public models and are updated to remove the obsolete separate spacer.

**Tech Stack:** Python 3, CadQuery/OpenCascade, standard-library `unittest`, python-docx release pipeline.

**Spec:** `docs/superpowers/specs/2026-09-10-generator-coil-guide-v5-1.md`

## Global Constraints

- Preserve the accepted rotor blade and bayonet geometry.
- Keep both nominal magnet-to-active-winding gaps at 1.5 mm.
- Keep stationary and rotating ownership explicit and collision-audited.
- Retain prototype and non-waterproof warnings.
- Run CadQuery tests through `scripts/run_geometry.py`; the Windows OCP runtime may return a native nonzero teardown status after unittest reports `OK`, which must be reported separately.

---

### Task 1: Four aligned cover fasteners

**Files:**
- Modify: `tests/test_generator_housing.py`
- Modify: `src/windwall/generator_housing.py`

**Interfaces:**
- Consumes: `GeneratorHousingParts.bottom_mount_tabs`, `cover_fasteners`
- Produces: four independent `CoverFastener` paths aligned angularly with four `BottomMountTab` paths

- [ ] **Step 1: Write failing tests** asserting four cover fasteners, matching normalized radial axes, separate radii, clear tool paths, and fused reinforcement between each boss, shell and tab.
- [ ] **Step 2: Run** `python scripts/run_geometry.py -m unittest tests.test_generator_housing -v` and verify failure because six diagonal fasteners exist.
- [ ] **Step 3: Implement** cardinal fastener axes and continuous boss-to-tab reinforcement in `generator_housing.py`.
- [ ] **Step 4: Run the same test command** and verify all housing tests report `OK`.

### Task 2: Open serpentine winding guide

**Files:**
- Modify: `tests/test_generator_housing.py`
- Modify: `src/windwall/generator_housing.py`
- Modify: `tests/test_generator.py`

**Interfaces:**
- Consumes: `build_coil_cassette(DesignParameters)` and `GeneratorHousingParts.winding_volume`
- Produces: one printable cassette solid with 18 rounded guide islands and a collision-free rotating center passage

- [ ] **Step 1: Write failing tests** that detect 18 alternating guide stations at the reference angular pitch, verify an open winding path and lead access, and verify no guide intersects the active winding envelope or rotating keep-out.
- [ ] **Step 2: Run the focused housing tests** and verify failure because the cassette currently has only annular walls.
- [ ] **Step 3: Implement** rounded guide islands fused to the cassette floor, with alternating inner/outer winding turns and lead gates at the cable passage.
- [ ] **Step 4: Run focused housing and generator tests** and verify `OK`.

### Task 3: Integral lower-rotor sleeve

**Files:**
- Modify: `tests/test_generator.py`
- Modify: `src/windwall/generator.py`
- Modify: `src/windwall/export.py`
- Modify: `tests/test_exports.py`

**Interfaces:**
- Consumes: `build_lower_magnet_rotor(DesignParameters)`
- Produces: lower rotor with fused 12 mm OD sleeve and no separate `spacer` assembly/export part

- [ ] **Step 1: Write failing tests** for connected sleeve geometry, 8.8 mm passage, 17.85 mm nominal reach, preserved nut access, and absence of a separate spacer export.
- [ ] **Step 2: Run generator/export tests** and verify failure because the spacer is separate.
- [ ] **Step 3: Fuse the sleeve** in `build_lower_magnet_rotor`, remove the separate assembly/export body, and keep it in rotating collision checks as part of the rotor.
- [ ] **Step 4: Run generator/export tests** and verify `OK`.

### Task 4: Release artifacts and documentation

**Files:**
- Modify: `README.md`
- Modify: `scripts/manual/manual_data.py`
- Modify: `scripts/manual/build_manual.py`
- Modify: relevant release validation tests
- Regenerate: `release/v5/**`

**Interfaces:**
- Consumes: revised public CAD builders and release scripts
- Produces: synchronized STL, STEP, drawings, English README and six-language DOCX set

- [ ] **Step 1: Update validation tests** for the new part inventory, four fasteners, serpentine guide and integral sleeve; verify they fail against the old artifacts.
- [ ] **Step 2: Update human-readable source documentation** to explain winding around the 18 guides and removal of the separate sleeve.
- [ ] **Step 3: Rebuild the V5 release** with `scripts/build_v5.py` and update the deterministic release index.
- [ ] **Step 4: Run all tests and artifact audits**, inspect the revised generator drawings, and record the native teardown limitation separately from unittest results.

### Task 5: Review and integration

**Files:**
- Review all modified files and generated artifacts

**Interfaces:**
- Consumes: completed V5.1 worktree
- Produces: reviewable commit ready for integration and later push

- [ ] **Step 1: Run cleanup checks** for stale spacer references, obsolete six-fastener wording, dead code and untracked generated files.
- [ ] **Step 2: Run fresh focused and full verification commands** and inspect `git diff --check` plus worktree status.
- [ ] **Step 3: Commit the focused V5.1 change** only after verification evidence is available.
- [ ] **Step 4: Present integration status** without pushing until the completed branch has passed review and the repository state is confirmed.

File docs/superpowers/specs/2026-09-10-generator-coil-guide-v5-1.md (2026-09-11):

# Generator Coil Guide V5.1 Design

## Scope

Revise the stationary generator package and lower magnet rotor without changing
the accepted rotor blade or bayonet geometry.

## Coil cassette

- Replace the empty winding annulus with 18 rounded, open-top serpentine guide
  islands following the functional layout measured in the supplied reference
  `2 Coil_Former.stl`.
- Keep the guide open for experimental wire diameters and turn counts, including
  the user's existing 0.18 mm enamelled copper wire.
- Keep the stationary cassette clear of the rotating central sleeve and retain
  the existing keyed, radially piloted, cover-retained cassette interface.
- Route both winding leads to the existing non-waterproof side cable passage.
- Treat the represented winding as an envelope, not a validated electrical
  design or a model of individual wires.

## Housing and cover fasteners

- Use exactly four M4 cover fasteners at 0, 90, 180 and 270 degrees.
- Put each M4 boss on the same radial axis as one separate lower frame-mount
  hole; the cover fastener must not also fasten the housing to the wood frame.
- Connect each boss structurally to the wall and bottom mounting tab so the boss
  reinforces the tab.
- Preserve top driver access, captive nut access from below, and independent
  access to the frame screw holes.

## Lower magnet rotor sleeve

- Fuse the existing 12 mm OD rotating spacer envelope to the top of the lower
  magnet rotor.
- Preserve the 8.8 mm M8 clearance passage and rear-open captive M8 nut pocket.
- Extend the fused sleeve from the lower magnet face to the lower face of the
  upper M8 nut, currently 17.85 mm nominal height.
- Remove the separate printable spacer from exports, assembly inventory and
  documentation while retaining explicit collision auditing of the fused sleeve.

## Constraints

- Nominal upper and lower magnet-face-to-active-winding gaps remain 1.5 mm.
- Housing, cassette, cover and winding stay stationary; both magnet rotors,
  shaft, nuts and fused sleeve rotate.
- The result remains a non-waterproof, physically uncalibrated prototype.
- Generated STL, STEP, drawings, README and all released manuals must agree with
  the revised CAD.

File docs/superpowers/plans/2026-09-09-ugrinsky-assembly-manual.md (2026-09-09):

# Ugrinsky Wind Wall Assembly Manual Implementation Plan

> **For agentic workers:** REQUIRED SUB-SKILL: Use superpowers:subagent-driven-development (recommended) or superpowers:executing-plans to implement this plan task-by-task. Steps use checkbox (`- [ ]`) syntax for tracking.

**Goal:** Produce a visually verified German DOCX and PDF construction manual with complete bills of materials, CAD-derived exploded drawings, generator assembly guidance, and an empirical serpentine-coil procedure.

**Architecture:** Extract one deterministic manual data model from the existing design parameters and release manifest, render all technical figures from the actual CAD solids plus explicit schematic overlays, then generate DOCX and PDF from that shared content. Automated audits enforce BOM-to-callout coverage, drawing references, electrical uncertainty labels, and artifact presence; page PNG review provides the final layout gate.

**Tech Stack:** Existing CadQuery/OCP environment, bundled Python runtime with python-docx and Pillow, Matplotlib for CAD projections and schematics, bundled LibreOffice renderer, Poppler, unittest.

**Spec:** `docs/superpowers/specs/2026-09-09-ugrinsky-assembly-manual-design.md`

## Global Constraints

- Write the manual in German for a maker without CAD experience.
- Deliver `output/Ugrinsky-Wind-Wall-Bauanleitung.docx` and `output/pdf/Ugrinsky-Wind-Wall-Bauanleitung.pdf` with identical released content.
- Use the current release manifest and CadQuery sources as the mechanical source of truth.
- Show one base, five standard stages, one top stage, one closure and one separate lower magnet rotor.
- Preserve CCW wind rotation and locking; insertion begins 18 degrees clockwise from the aligned locked pose.
- Use 36 nominal 10 x 2 mm magnets in 18 pockets per rotor, with alternating N-S polarity and opposed attraction.
- Start with the available nominal 0.18 mm enamelled copper wire, measure every wire across its enamel, and test 20, 40 and 80 turns per diameter where the coil fits without forced packing.
- Never designate a final wire diameter or winding count before comparative voltage, load, resistance and temperature measurements.
- Do not specify a final winding count, controller, fuse, cable, rectifier or dump-load rating without measured electrical data.
- State that the generator must not be connected directly to the 48 V lead-acid battery.
- Mark physical fit, PLA strength, magnet retention, bearing retention, outdoor service and final electrical performance as unverified.
- Generate figures at print-readable resolution and inspect every rendered page before delivery.

---

### Task 1: Manual data model and coverage contract

**Files:**
- Create: `scripts/manual/__init__.py`
- Create: `scripts/manual/manual_data.py`
- Create: `tests/test_manual_data.py`
- Modify: `.gitignore`

**Interfaces:**
- Consumes: `windwall.parameters.DEFAULT_PARAMETERS`, `build/manifest.json`.
- Produces: `load_manual_data(project_root: Path) -> dict`, stable BOM item IDs `P01` through `P05`, `H01` onward, drawing IDs `E01` onward, and validation helpers used by figure and document builders.

- [ ] **Step 1: Write the failing data-contract tests**

```python
def test_manual_data_matches_release_and_selected_hardware():
    data = load_manual_data(PROJECT_ROOT)
    assert data['dimensions']['loaded_height_mm'] == 487.84
    assert data['printed_parts']['P02']['quantity'] == 5
    assert data['hardware']['H01']['description'] == 'M8 Gewindestange'
    assert data['hardware']['H10']['quantity'] == 36
    assert data['hardware']['H10']['size'] == '10 x 2 mm'

def test_every_bom_item_has_a_drawing_callout():
    data = load_manual_data(PROJECT_ROOT)
    called_out = {item for drawing in data['drawings'].values() for item in drawing['items']}
    assert set(data['printed_parts']) | set(data['hardware']) <= called_out
```

- [ ] **Step 2: Run the tests and verify RED**

Run: `$env:PYTHONPATH='src;.'; .\.venv\Scripts\python.exe scripts\run_geometry.py -m unittest tests.test_manual_data -v`

Expected: import failure because `scripts.manual.manual_data` does not exist.

- [ ] **Step 3: Implement the centralized data model**

```python
def load_manual_data(project_root: Path) -> dict:
    manifest = json.loads((project_root / 'build/manifest.json').read_text(encoding='utf-8'))
    audit = manifest['assembly_audit']
    return {
        'dimensions': {
            'loaded_height_mm': round(audit['aerodynamic_height_mm'], 2),
            'rod_length_mm': round(audit['shaft_z_bounds_mm'][1] - audit['shaft_z_bounds_mm'][0], 2),
            'air_gap_mm': audit['upper_generator_air_gap_mm'],
        },
        'printed_parts': PRINTED_PARTS,
        'hardware': HARDWARE,
        'drawings': DRAWINGS,
        'validation_status': VALIDATION_STATUS,
    }
```

Define explicit German descriptions, quantities, selection status, source file paths and drawing membership. Include required M8 hardware, twelve radial M3 retainers, two closure screws, bearing/spacer placeholders, 36 magnets, copper wire, insulation, adhesive, rectifier, protection, controller and dump load. Label unresolved ratings as `Nach Messung auswählen`.

- [ ] **Step 4: Add output ignores and validate the model**

Add `/output/` and `/tmp/manual/` to `.gitignore`. Run the Task 1 tests and `git diff --check`.

Expected: all tests pass and the tree has no whitespace errors.

- [ ] **Step 5: Commit**

```powershell
git add .gitignore scripts/manual tests/test_manual_data.py
git commit -m "feat: define assembly manual data model"
```

---

### Task 2: CAD-derived exploded drawings

**Files:**
- Create: `scripts/manual/cad_figures.py`
- Create: `tests/test_manual_cad_figures.py`
- Output: `output/manual-figures/E01-gesamt-explosion.png`
- Output: `output/manual-figures/E02-generator-explosion.png`
- Output: `output/manual-figures/E03-basisrotor.png`
- Output: `output/manual-figures/E04-standardverbindung.png`
- Output: `output/manual-figures/E05-topabschluss.png`
- Output: `output/manual-figures/E06-schnitt-luftspalt.png`

**Interfaces:**
- Consumes: `load_manual_data`, `build_locked_rotor_assembly`, `build_exploded_rotor_assembly`, generator and module builders.
- Produces: `render_cad_figures(project_root: Path, output_dir: Path) -> list[FigureRecord]`, where `FigureRecord` contains drawing ID, path, caption and callout IDs.

- [ ] **Step 1: Write failing rendering and callout tests**

```python
def test_cad_figures_cover_the_mechanical_bom(tmp_path):
    records = render_cad_figures(PROJECT_ROOT, tmp_path)
    assert [record.drawing_id for record in records] == ['E01','E02','E03','E04','E05','E06']
    assert all(record.path.stat().st_size > 50_000 for record in records)
    assert {'P01','P02','P03','P04','P05','H01','H10'} <= {
        item for record in records for item in record.callouts
    }
```

- [ ] **Step 2: Run the tests and verify RED**

Run: `$env:PYTHONPATH='src;.'; .\.venv\Scripts\python.exe scripts\run_geometry.py -m unittest tests.test_manual_cad_figures -v`

Expected: import failure because `cad_figures.py` does not exist.

- [ ] **Step 3: Implement a reusable projection renderer**

```python
@dataclass(frozen=True)
class FigureRecord:
    drawing_id: str
    path: Path
    caption: str
    callouts: tuple[str, ...]

def project_solids(parts: Sequence[RenderedPart], destination: Path, title: str) -> None:
    """Tessellate real solids, depth-sort triangles and add numbered leaders."""
```

Use one fixed isometric camera, consistent colors for rotor, stationary,
hardware and magnetic parts, and leader labels outside the geometry. Render at
minimum 2200 pixels on the long side. Do not alter production geometry.

- [ ] **Step 4: Build the six mechanical views**

Separate the seven stages cumulatively in E01. E02 separates lower rotor,
generator base, bearing references, stator former/cover and integrated upper
rotor. E04 shows insertion at -18 degrees beside the locked CCW stop and labels
the three lugs, two drivers and two retainers. E06 is a sectional drawing with
the nominal 1.5 mm gaps and flush-magnet condition.

- [ ] **Step 5: Run tests and visually inspect all six PNGs**

Run the Task 2 tests, then inspect every generated PNG at original resolution.
Reject clipped labels, hidden components, ambiguous leaders and unreadable
dimensions.

- [ ] **Step 6: Commit**

```powershell
git add scripts/manual/cad_figures.py tests/test_manual_cad_figures.py
git commit -m "feat: render manual exploded CAD drawings"
```

---

### Task 3: Magnet and serpentine-coil schematics

**Files:**
- Create: `scripts/manual/electrical_figures.py`
- Create: `tests/test_manual_electrical_figures.py`
- Output: `output/manual-figures/E07-magnetpolung.png`
- Output: `output/manual-figures/E08-serpentinenpfad.png`
- Output: `output/manual-figures/E09-wickelschablone.png`
- Output: `output/manual-figures/E10-messaufbau.png`
- Output: `output/manual-figures/E11-ladekette.png`

**Interfaces:**
- Consumes: magnet count/pitch and provisional coil-former envelope from `load_manual_data`.
- Produces: `render_electrical_figures(project_root: Path, output_dir: Path) -> list[FigureRecord]` and `estimate_final_turns(test_turns: int, measured_v_rms: float, target_v_rms: float) -> int`.

- [ ] **Step 1: Write failing topology and calculation tests**

```python
def test_polarity_alternates_and_opposed_faces_attract():
    top, bottom = magnet_polarities(18)
    assert all(top[i] != top[(i + 1) % 18] for i in range(18))
    assert all(top[i] != bottom[i] for i in range(18))

def test_turn_estimate_rounds_up_and_rejects_missing_measurement():
    assert estimate_final_turns(20, 8.0, 60.0) == 150
    with self.assertRaises(ValueError):
        estimate_final_turns(20, 0.0, 60.0)

def test_matrix_uses_measured_wire_diameters_and_three_turn_counts():
    assert build_test_matrix([0.18, 0.31]) == [
        (0.18, 20), (0.18, 40), (0.18, 80),
        (0.31, 20), (0.31, 40), (0.31, 80),
    ]
```

- [ ] **Step 2: Run the tests and verify RED**

Run: `$env:PYTHONPATH='src;.'; .\.venv\Scripts\python.exe scripts\run_geometry.py -m unittest tests.test_manual_electrical_figures -v`

Expected: import failure because `electrical_figures.py` does not exist.

- [ ] **Step 3: Implement polarity and winding-path models**

```python
def magnet_polarities(count: int) -> tuple[tuple[str, ...], tuple[str, ...]]:
    if count <= 0 or count % 2:
        raise ValueError('Magnet count must be positive and even')
    top = tuple('N' if index % 2 == 0 else 'S' for index in range(count))
    bottom = tuple('S' if pole == 'N' else 'N' for pole in top)
    return top, bottom

def estimate_final_turns(test_turns: int, measured_v_rms: float, target_v_rms: float) -> int:
    if test_turns <= 0 or measured_v_rms <= 0 or target_v_rms <= 0:
        raise ValueError('Turns and voltages must be positive')
    return math.ceil(test_turns * target_v_rms / measured_v_rms)

def build_test_matrix(measured_diameters_mm: Sequence[float]) -> list[tuple[float, int]]:
    if not measured_diameters_mm or any(value <= 0 for value in measured_diameters_mm):
        raise ValueError('Measured wire diameters must be positive')
    return [(diameter, turns) for diameter in measured_diameters_mm for turns in (20, 40, 80)]
```

Generate an 18-leg continuous serpentine path alternating between inner and
outer radii. Show start `A1`, finish `A2`, one unambiguous winding direction and
the 20/40/80-turn test series without implying conductor packing or fit.

- [ ] **Step 4: Render the five electrical figures**

E07 shows both facing rotor maps and the attraction rule. E08 shows the active
radial legs relative to alternating poles. E09 shows a safe board-and-insulated-
pin jig. E10 shows tachometer, multimeter, bridge rectifier only where relevant,
and measurement table fields. E11 shows generator to rectifier to wind charge
controller/dump load to fused 48 V battery bank and explicitly crosses out a
direct generator-to-battery connection.

- [ ] **Step 5: Verify images and tests**

Run Task 3 tests and inspect E07-E11 at original resolution. Confirm polarity is
encoded by both letters and color, all leads are labelled, and no final voltage
or component rating is presented as measured.

- [ ] **Step 6: Commit**

```powershell
git add scripts/manual/electrical_figures.py tests/test_manual_electrical_figures.py
git commit -m "feat: illustrate magnets and serpentine winding"
```

---

### Task 4: German DOCX manual

**Files:**
- Create: `scripts/manual/build_manual.py`
- Create: `tests/test_manual_document.py`
- Output: `output/Ugrinsky-Wind-Wall-Bauanleitung.docx`

**Interfaces:**
- Consumes: manual data and all `FigureRecord` lists.
- Produces: `build_manual(project_root: Path, output_path: Path) -> Path`.

- [ ] **Step 1: Load the bundled document runtime and required instructions**

Use `load_workspace_dependencies`. Read the document skill's
`tasks/create_edit.md`, `tasks/images_figures.md`,
`tasks/headings_numbering.md`, `tasks/tables_spreadsheets.md`,
`tasks/accessibility_a11y.md`, and `tasks/verify_render.md` completely. Run the
required artifact-operation marker exactly once immediately before authoring.

- [ ] **Step 2: Write failing structural-document tests**

```python
def test_manual_contains_required_sections_figures_and_warnings():
    document = Document(OUTPUT_DOCX)
    text = '\n'.join(paragraph.text for paragraph in document.paragraphs)
    assert 'Serpentinen Testwicklung' in text
    assert 'nicht direkt mit dem Akku verbinden' in text
    assert 'N_final = N_test' in text
    assert len(document.inline_shapes) >= 11
    assert len(document.tables) >= 4

def test_all_bom_and_figure_ids_appear_in_document():
    text = extract_docx_text(OUTPUT_DOCX)
    data = load_manual_data(PROJECT_ROOT)
    assert all(item_id in text for item_id in (*data['printed_parts'], *data['hardware']))
    assert all(drawing_id in text for drawing_id in data['drawings'])
```

- [ ] **Step 3: Run the tests and verify RED**

Expected: failure because the DOCX and builder do not exist.

- [ ] **Step 4: Implement the document builder**

Use A4 portrait pages, 18 mm side margins, restrained black/blue technical
styling, Word Title and numbered Heading styles, captions below figures,
repeating BOM table headers, page numbers and descriptive alt text. Use
landscape sections only for drawings or BOM tables that cannot remain readable
in portrait orientation.

Write explicit sequential instructions for printing, coupon checks, magnet dry
layout, generator stack, measuring each enamelled wire diameter, winding the
20/40/80-turn test matrix where it fits, enamel preparation,
continuity/resistance checks, common-RPM open-circuit and defined-load
measurements, temperature recording, turn calculation, potting decision, rotor
stacking and commissioning. Include blank comparison tables rather than
invented results.

- [ ] **Step 5: Build and run structural tests**

Generate the DOCX with the bundled Python runtime. Run
`tests/test_manual_document.py` and the packaged heading, image and accessibility
audits. Fix missing alt text, nonrepeating table headers, unresolved IDs or
heading-level errors.

- [ ] **Step 6: Commit source and tests**

```powershell
git add scripts/manual/build_manual.py tests/test_manual_document.py
git commit -m "feat: build German Ugrinsky assembly manual"
```

---

### Task 5: PDF release and full visual QA

**Files:**
- Create: `scripts/manual/verify_manual.py`
- Create: `tests/test_manual_release.py`
- Output: `output/pdf/Ugrinsky-Wind-Wall-Bauanleitung.pdf`
- Output: `tmp/manual/rendered/page-*.png`

**Interfaces:**
- Consumes: final DOCX and bundled render/Poppler paths.
- Produces: `verify_manual_release(docx_path: Path, pdf_path: Path, render_dir: Path) -> dict` containing page count, figure/BOM coverage, missing-text checks and render dimensions.

- [ ] **Step 1: Write failing release tests**

```python
def test_released_pdf_matches_docx_structure_and_has_rendered_pages():
    report = verify_manual_release(DOCX, PDF, RENDER_DIR)
    assert report['pdf_pages'] == report['rendered_pages']
    assert report['pdf_pages'] >= 16
    assert report['missing_required_phrases'] == []
    assert report['blank_or_tiny_pages'] == []
```

- [ ] **Step 2: Run the tests and verify RED**

Expected: failure because no PDF release or verifier exists.

- [ ] **Step 3: Render DOCX and emit PDF**

Run the packaged `render_docx.py` using the absolute bundled runtime paths and
`--emit_pdf`. Copy the verified PDF to the stable `output/pdf/` name. Never use
the user's desktop LibreOffice installation.

- [ ] **Step 4: Implement structural PDF verification**

Use `pypdf` to confirm page count and metadata, `pdfplumber` to extract required
headings/warnings, and Poppler page PNGs to reject blank or implausibly small
pages. Confirm the DOCX and PDF contain the same drawing captions and BOM IDs.

- [ ] **Step 5: Inspect every rendered page at 100 percent**

Review all page PNGs in order. Fix and rerender any clipped tables, overlapping
leaders, orphaned headings, split procedural warnings, missing glyphs, poor
figure scale or inconsistent page numbering. Repeat until every page passes.

- [ ] **Step 6: Run all manual and project tests**

Run all `tests/test_manual_*.py`, then the complete existing 93-test suite with
the supplied reference STL. Record the known native OCP shutdown result
separately from the unittest `OK` result.

- [ ] **Step 7: Final artifact audit and documentation update**

Add a short README section linking the manual outputs and stating their
prototype status. Confirm DOCX, PDF and every final figure exist and are
nonempty. Run `git diff --check` and scan source/document text for placeholders,
unresolved file paths and unsupported final electrical ratings.

- [ ] **Step 8: Commit**

```powershell
git add README.md scripts/manual/verify_manual.py tests/test_manual_release.py
git commit -m "docs: release illustrated Ugrinsky construction manual"
```

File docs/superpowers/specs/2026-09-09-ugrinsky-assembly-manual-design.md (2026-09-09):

# Ugrinsky Wind Wall assembly manual design

## Purpose

Create a German-language construction manual for the seven-stage Ugrinsky Wind
Wall prototype. Deliver both an editable DOCX and a print-ready PDF. The manual
must connect every printed and purchased part to numbered exploded drawings,
explain the mechanically validated assembly order, and provide a safe empirical
method for developing a serpentine stator winding for a future 48 V lead-acid
battery system.

The manual is for a technically interested maker using a Bambu Lab P2S with a
0.4 mm nozzle. It must remain usable without CAD experience.

## Deliverables

- `output/Ugrinsky-Wind-Wall-Bauanleitung.docx`
- `output/pdf/Ugrinsky-Wind-Wall-Bauanleitung.pdf`
- high-resolution source figures under `output/manual-figures/`

The DOCX and PDF contain the same released content. Intermediate renderings and
QA files are not deliverables.

## Document structure

1. Scope, prototype status, safety and key dimensions.
2. Printed-parts bill of materials with quantities and file references.
3. Purchased-parts bill of materials, separating required, provisional and
   electrically selected parts.
4. PLA prototype settings for the P2S and notes for later ASA production.
5. Preparation and coupon tests.
6. Generator mechanical assembly.
7. Magnet installation and polarity verification.
8. Serpentine test-coil construction.
9. Electrical measurement and final-turn calculation.
10. Seven-stage rotor assembly and CCW self-tightening bayonets.
11. Top clamp, closure, alignment and balance checks.
12. Commissioning, inspection schedule and troubleshooting.
13. Appendices containing formulas, measurement sheets and drawing index.

## Mechanical content

The manual uses the current parametric model and release manifest as its
mechanical source of truth. It documents one base rotor module, five identical
standard modules, one top module, one top closure and one separate lower magnet
rotor. The upper magnet carrier remains integrated into the base module.

The ordinary M8 threaded rod remains continuous through the entire rotor. M8
nuts and washers transmit axial clamping force. Twelve radial M3
self-threading screws are reverse-release retainers only and must not pull the
joints together or carry axial preload. The loaded module pitch is 69.64 mm,
the seven-stage aerodynamic height is 487.84 mm, and the modeled rod envelope
is 559.64 mm. Actual rod cut length is determined from measured bearings,
washers, nuts and end support geometry.

Viewed from above, wind-driven rotation and bayonet locking are counterclockwise.
Each upper stage enters 18 degrees clockwise from its final aligned position and
locks counterclockwise. The source blade retains 60 degrees of internal twist,
so each aligned stage produces a documented minus-60-degree seam phase jump.

## Exploded drawings

Figures are generated from actual STEP/CadQuery solids, not redrawn silhouettes.
Use a consistent isometric projection, restrained group colors, numbered leader
lines and a legend linked to the bills of materials. Required views are:

- complete seven-stage wind module;
- generator stack with stationary and rotating groups separated;
- upper integrated magnet carrier and base rotor interface;
- lower magnet rotor, spacer, bearing and clamp hardware;
- one standard rotor joint showing three bayonet lugs, two drivers and two
  radial retainers;
- top rotor, washer, exposed M8 nut and removable closure;
- magnet polarity map for both 18-pocket rotors;
- serpentine winding path, winding jig and lead identification;
- locked versus insertion orientation viewed from above;
- critical sectional views for shaft, air gaps and pocket floors.

Every figure identifies whether shown non-printed solids are actual selected
hardware or provisional reference envelopes.

## Generator and magnets

Use 36 nominal 10 x 2 mm neodymium disc magnets, 18 per rotor. The existing
carrier pockets are nominally 11 mm diameter and 2 mm deep. The manual requires
the 10.8, 11.0 and 11.2 mm pocket coupon to be printed first. Adhesive,
centrifugal retention and magnet grade are not declared validated.

Adjacent magnets on each rotor alternate north and south. At every opposed
position, the upper and lower magnets present opposite poles toward each other
and therefore attract across the stationary winding. The polarity procedure
uses a marked reference magnet or compass and includes a complete dry-layout
check before adhesive is applied.

The nominal 1.5 mm air gaps are valid only for flush or recessed magnets.
Installed protrusion is measured and recorded before rotation.

## Serpentine winding method

The stator starts with one continuous air-core serpentine test winding. The
conductor alternates between the inner and outer winding radii around the full
circumference so successive active radial legs cross successive alternating
magnetic poles. All turns follow the same path and winding direction. Start and
finish leads are labelled before removal from the jig.

The test program starts with the user's existing nominal 0.18 mm enamelled
copper wire. Every spool, including additional ordered diameters, is measured
across the enamel with a micrometer before use; nominal labels are recorded but
never substituted for the measured diameter. No wire diameter is designated as
the final choice in advance.

For each available diameter, wind separate 20-, 40- and 80-turn serpentine test
coils when they fit the former without forced packing. If a planned coil does
not fit, record that result rather than compressing or damaging the enamel. The
manual shows a reusable printable or board-and-insulated-pin jig, controlled
bend radii, temporary binding, continuity testing, placement in the former and
conservative potting guidance. It prohibits sharp metal tools against enamel
and records measured diameter, turn count, wire length, coil dimensions, DC
resistance and temperature.

Each test winding is driven at the same set of measured rotor speeds. Record
open-circuit RMS voltage and frequency, then voltage, current and temperature
under the same defined resistive test loads. Calculate voltage per turn,
resistance per metre, internal voltage drop and approximate copper loss so
different wire diameters and turn counts remain comparable. For a chosen design
speed, estimate final turns with:

`N_final = N_test * V_ac_target / V_ac_test`

The target voltage is derived from the chosen rectifier and 48 V lead-acid
charge controller, not assumed to be exactly 48 V. Wire gauge, final winding
count, series or parallel grouping and thermal rating remain conditional on the
test results and available stator volume. If the calculated winding does not fit
or has excessive resistance, the manual directs redesign rather than silently
reducing safety margins.

## Electrical boundary and safety

The generator must not connect directly to the battery. The conceptual chain is
generator, suitably rated rectifier, overcurrent protection, wind-generator
charge controller with diversion or dump-load capability, battery-side fuse and
48 V lead-acid bank. Exact controller, rectifier, cable, fuse and dump-load
ratings require measured generator voltage, current, speed and battery
configuration and therefore appear as selection fields rather than invented
part numbers.

The manual warns about rotating parts, strong magnets, stored battery energy,
short-circuit current, hydrogen ventilation, polarity mistakes, overspeed,
water ingress and hot windings. First electrical tests use current limiting and
no unattended outdoor operation.

## Evidence and uncertainty

Mechanical dimensions and topology come from the current source, tests and
release manifest. Original STL measurements are identified separately from
reconstruction decisions. External references may explain the serpentine
principle and general axial-flux practice, but the manual must not repeat
unverified performance claims.

Each uncertain item is marked as one of:

- verify by coupon or measurement;
- provisional reference geometry;
- select after electrical test;
- not yet approved for outdoor service.

## Verification

- Generate every figure at print-readable resolution.
- Build the DOCX with headings, captions, repeating table headers, page numbers
  and accessible alternative text.
- Render the DOCX to page PNGs and PDF using the bundled document runtime.
- Inspect every rendered page for clipping, overlap, unreadable labels, broken
  tables and missing images.
- Reopen the PDF, confirm its page count and extract text as a structural check.
- Confirm that all BOM item numbers appear in at least one exploded drawing and
  every drawing number is referenced in the instructions.
- Confirm that no unmeasured electrical value is presented as a validated final
  design value.

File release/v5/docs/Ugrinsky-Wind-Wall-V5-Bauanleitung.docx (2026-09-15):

# Ugrinsky Wind Wall V5 Bauanleitung

Montage und Spulenversuche für den PLA Prototyp

# 1 Zweck und Grenzen

Diese Anleitung führt durch Passproben, Druck, Montage des siebenstufigen Rotors und vergleichbare Spulenversuche. Baue zuerst einen geschützten Werkstattaufbau. Erst reale Messungen erlauben die Auswahl der Wicklung, der Magnetbefestigung und der Ladeelektronik.

Prototypstatus. V5 ist physisch nicht validiert. CAD-Prüfungen bestätigen geometrische Eigenschaften, aber keine sichere Drehzahl, Dauerfestigkeit, Leistung oder Eignung für unbeaufsichtigten Außenbetrieb. Die Passungen sind keine freigegebene Presspassung. Der seitliche Kabelausgang und das Gehäuse sind nicht wasserdicht.

Elektrische Grenze. Den Generator nicht direkt an einen 48-V-Bleiakku anschließen. Für die ersten Versuche ausschließlich einen geschützten Messaufbau mit definierter, passend bemessener Last verwenden.

Unvalidiertes Konzeptbild einer modernen Haus- und Gartenlandschaft mit einem Zaunelement aus zehn schlanken vertikalen Ugrinsky Rotoren

Konzeptbild Ein mögliches Zaunelement mit zehn Ugrinsky Rotoren in einer Gartenumgebung

Merkmal | V5 Nennwert
Rotorstufen | 7: 1 Base, 5 Standard, 1 Top
Rotordurchmesser | 122 mm
Stufenteilung und Rotorhöhe | 70 × 490 mm
Verlängerte Wellenhülle | 555,8 mm; kein verbindliches Zuschnittmaß
Druckkörper | 12 aus 8 unterschiedlichen STL-Dateien

## Gesamtaufbau verstehen

E15. Sieben Rotorstufen und Generator sind zwischen unterem und oberem Holzriegel montiert. Holz und Holzschrauben nicht drucken, sondern vor Ort auslegen. CAD V5; Passung, Elektrik und Betrieb sind unvalidiert. Oberer Holzriegel · nicht drucken 608-Halter · 4 Schrauben von unten Rotor · 1 Base + 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

E15 Sieben Rotorstufen und Generator sind zwischen unterem und oberem Holzriegel montiert.

Ocker bezeichnet den rotierenden Strang. Türkis bezeichnet stationäre Druckteile. Violett kennzeichnet Lagerbereiche; deren Wälzkörper und Laufringe haben unterschiedliche Bewegungen. Graue Holz-, Schrauben- und Freiraumreferenzen sind keine Druckteile.

Die beiden Magnetträger drehen gemeinsam mit Welle, M8-Klemmung und Rotorstapel. Spule, Kassette, Gehäuse, Deckel und oberer Halter bleiben stationär. Der untere Magnetrotor läuft innerhalb des Gehäuses unterhalb der stationären Spule.

Zum Nachschlagen: Kapitel 2 und 3 enthalten Teile und Kaufhardware; 4 und 5 Druck und Passproben; 6 bis 9 Wicklung und Montage; 10 und 11 Messung und Inbetriebnahme; 12 und 13 Wartung, Fehlersuche und Versuchsprotokoll.

# 2 Druckteile und Dateien

Die Mengen gelten für einen vollständigen Rotor einschließlich Generatorgehäuse und oberem Halter. Der obere Magnetträger ist in der Base integriert. STL-Dateien liegen unter release/v5/stl/, die zugehörigen STEP-Dateien unter release/v5/step/.

Stück | Druckteil | STL Datei | STEP Datei
1 | Base mit oberem Magnetträger | base_rotor_module.stl | base_rotor_module.step
5 | Standardmodul | standard_rotor_module.stl | standard_rotor_module.step
1 | Topmodul | top_rotor_module.stl | top_rotor_module.step
1 | Unterer Magnetrotor | lower_magnet_rotor.stl | lower_magnet_rotor.step
1 | Generatorgehäuse | generator_housing.stl | generator_housing.step
1 | Spulenkassette | coil_cassette.stl | coil_cassette.step
1 | Stationärer Deckel | generator_cover.stl | generator_cover.step
1 | Oberer Lagerhalter | top_support.stl | top_support.step

Base, Standard, Top und unterer Magnetrotor sind rotierend. Gehäuse, Spulenkassette, Generator-Deckel und oberer Lagerhalter sind stationär. Die Release-STLs stehen am Druckbett auf Z = 0; dies ist keine automatisch optimierte Druckorientierung.

## Passproben und Baugruppen

Alle folgenden Coupons einmal für die erste Passprüfung drucken. Wiederhole sie bei verändertem Material, Profil oder Passmaß. Die Coupon-STLs liegen unter release/v5/coupons/, ihre STEP-Dateien unter release/v5/step/.

Stück | Coupon STL | Coupon STEP
1 | magnet_pocket_coupon.stl | magnet_pocket_coupon.step
1 | 51105_outer_seat_coupon.stl | 51105_outer_seat_coupon.step
1 | 25mm_pilot_coupon.stl | 25mm_pilot_coupon.step
1 | 608_seat_coupon.stl | 608_seat_coupon.step
1 | coil_cassette_segment_coupon.stl | coil_cassette_segment_coupon.step
1 | bayonet_male.stl | bayonet_male.step
1 | bayonet_female.stl | bayonet_female.step
1 | joint_male.stl | joint_male.step
1 | joint_female.stl | joint_female.step

## Baugruppen zur Kontrolle

release/v5/assembly/rotor_locked.step

release/v5/assembly/generator.step

release/v5/assembly/fence_assembly.step

Diese STEP-Baugruppen dienen zur Montagekontrolle. Die Datei fence_assembly.step enthält die verlängerte Welle für den oberen Halter. Holz und Kaufteile werden nicht aus Baugruppen heraus als Druckteile exportiert.

# 3 Kaufteile und Werkzeug

Die Tabelle beschreibt den geplanten Prototyp. Kaufe erst nach Abgleich mit den realen Teilen. Nennhüllen beweisen weder Gewindeeingriff noch Schraubenkopfsitz oder Tragfähigkeit.

Stück | Bauteil | Maß und Auswahl
1 | M8 Gewindestange | Verlängerte Welle für oberen 608; erst nach Trockenmontage ablängen
3 | M8 Muttern | Zwei formschlüssige Drehmomentmuttern und eine obere Klemmmutter
1 | Obere M8 Scheibe | 24 × 2 mm; Außenmaß und Dicke
36 | Magnete | Zwei Ringe mit je 18 Magneten; Projektziel 10 × 2 mm, reale Maße und Halterung prüfen
1 | Axiallager 51105 komplett | 25 × 42 × 11 mm
1 | Radiallager 608 | 8 × 22 × 7 mm
4 | M4 Deckelschrauben | Länge und Kopfform am realen Stapel prüfen; keine freigegebene Kataloglänge
4 | Gefangene M4 Muttern | Sechskant; vollständig in Gehäusetaschen einsetzen
4 | Holzschrauben unten | Wood screw 4 × 30 mm, flat head Ø9; do not print; unverified nominal envelope
4 | Holzschrauben oben | Wood screw 4 × 40 mm; do not print; V5 nominal envelope

Das 51105 wird als vollständiges Lager gekauft, einschließlich beider Scheiben und Wälzkörper. Diese werden in der CAD-Baugruppe getrennt dargestellt. Für die M4-Schrauben reale Durchstecklänge, Mutternhöhe, Kopf und Bodenabstand messen; die Hülle ist keine Kaufempfehlung für eine bestimmte Schraubenlänge.

## Material für Wicklung und Messung

Kupferlackdraht mit 0,18 mm Ausgangsdurchmesser, isolierte Anschlusslitzen, geeignete Löt- und Isoliermittel sowie eine erprobte Zugentlastung bereitlegen. Weitere Drahtdurchmesser erst vermessen. Befestigungs- und Vergussstoffe benötigen einen Verträglichkeitstest mit Drahtlack, Magnetbeschichtung und Druckmaterial.

Erforderliche Messmittel sind Messschieber, Mikrometer, Tiefenmaß, Fühlerlehren, Drehzahlmesser, geeignetes True-RMS-Multimeter, Temperaturfühler und definierte Leistungswiderstände. Für kleine Widerstände Messleitungswiderstand berücksichtigen oder Vierleitermessung nutzen. Passende M4- und M8-Werkzeuge, Schutzbrille und eine nichtmagnetische Montagehilfe ergänzen den Arbeitsplatz.

# 4 Druck vorbereiten

Beginne mit PLA und den Coupons auf dem Bambu P2S mit 0,4 mm Düse. Nutze das zum tatsächlich geladenen PLA passende Materialprofil. Als noch zu prüfenden Ausgangspunkt 0,20 mm Schichthöhe im Slicer betrachten. Temperatur, Kühlung, Wandlinien, Infill und Stützen erst anhand der Passproben und der vollständigen Schichtvorschau festlegen.

Die Rotorwand beträgt im CAD 2 mm. Stelle sicher, dass der Slicer dünne Wandbereiche lückenlos erzeugt. Materialstärke allein bestätigt keine Festigkeit; Orientierung und Layerhaftung bestimmen die tatsächliche Belastbarkeit mit.

Teilgruppe | Orientierung und Prüfung
Magnet und Lagercoupons | Taschen nach oben; Elephant Foot und Stützreste von Passflächen fernhalten.
Base | Magnettaschen öffnen in Einbaulage nach unten. Z-up und gewendete Lage im Slicer vergleichen; Taschen, Muttertasche und Blattübergänge prüfen.
Standard und Top | Exportierte Z-up-Lage prüfen; untere Klauen und obere Rastbahnen müssen frei und nach dem Druck zugänglich sein.
Unterer Magnetrotor | Magnettaschen nach oben; Rückentasche und Auflage auf dem Bett kontrollieren.
Gehäuse | Geschlossener Boden auf dem Bett, Öffnung nach oben; Laschen und Schraubkanäle vollständig prüfen.
Kassette | Auflage unten, Wicklungsraum nach oben; Schlüssel und Kabelöffnung ohne Grat.
Deckel und oberer Halter | Lagersitze nach oben bevorzugen, sofern Unterseite sauber abgestützt werden kann; keine Stützreste im Lagersitz.

Bajonettdächer und Hinterschneidungen benötigen eine überprüfte Brücke oder zugängliche Stützen. Lasse keine unentfernbaren Stützen in geschlossenen Rastbahnen. Prüfe jede Schicht der Vorschau vor dem Start; zuerst Coupons, anschließend eine reale Verbindung aus zwei Stufen, erst danach den ganzen Satz drucken.

ASA ist eine spätere Materialstufe. Nach dem Wechsel Passmaße, Verzug, Verbindungskräfte, Magnetbefestigung und Belastung erneut prüfen. Ein Materialwechsel allein gibt den Rotor nicht für Wetter, Wärme oder Dauerbetrieb frei. Für Verarbeitung und Belüftung die Hinweise des tatsächlich verwendeten Filaments und Druckers beachten.

# 5 Passproben und Lager prüfen

Miss die realen Lager, Magnete und Muttern vor dem Druck. Markiere Material, Profil und Orientierung auf jeder Probe. Ein maßhaltiger Coupon muss sich ohne Risse, Verkanten oder unkontrollierte Gewalt fügen lassen; die passende Auswahl dokumentieren und vor dem Druck großer Teile in die Konstruktion übernehmen.

Probe | Varianten im Release
51105 Außensitz | 42 / 42,2 / 42,4 mm
51105 Zentrierbund | 24,6 / 24,8 / 25 mm
608 Außensitz | 22 / 22,2 / 22,4 mm
Magnettaschen | 10,8 / 11 / 11,2 mm
Kassette Radialspiel | 0,3 / 0,35 / 0,4 mm

Beim Kassettensegment zuerst den männlichen Bogen bündig von der Platte freischneiden und die Schnittkante entgraten. Dann mit den Sitzsegmenten vergleichen. Der Coupon prüft radiales Spiel, nicht die fertige axiale Klemmung durch den Deckel.

Bajonettpaar und vollständiges Verbindungspaar getrennt testen. Die eigene straffe Bajonettpassung hat nominell 0,20 mm radial und 0,18 mm axial. Einführen, gegen den Uhrzeigersinn verriegeln und Rastung kontrollieren. Die vergrößerte Rastflanke ist nach dem Einrasten als praktisch dauerhaft vorgesehen; Rückdrehen oder Zerlegen kann Rastung oder Modul beschädigen. Kraft, sichtbare Risse, axiales Spiel und Blattnaht protokollieren; die Rastung nicht durch gewaltsames Rückdrehen freimachen.

## 51105 Passung und Orientierung

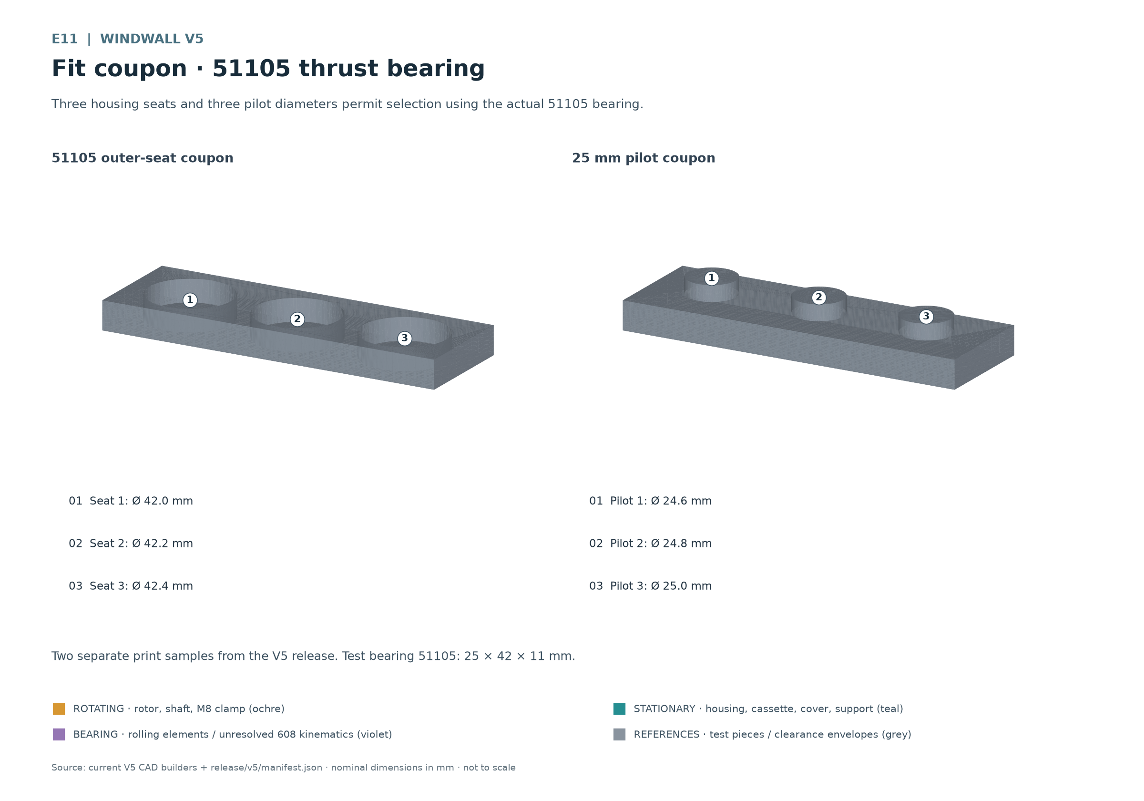
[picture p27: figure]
E11. Drei Gehäusesitze und drei Pilotdurchmesser erlauben die Auswahl mit dem realen 51105-Lager. Zwei getrennte Druckproben gemäß V5-Release. Prüflager 51105: 25 × 42 × 11 mm. Sitz 1: Ø 42,0 mm Sitz 2: Ø 42,2 mm Sitz 3: Ø 42,4 mm Pilot 1: Ø 24,6 mm Pilot 2: Ø 24,8 mm Pilot 3: Ø 25,0 mm

E11 Drei Gehäusesitze und drei Pilotdurchmesser erlauben die Auswahl mit dem realen 51105-Lager.

51105: 25 × 42 × 11 mm. Die Gehäusescheibe bleibt stationär im zentralen Deckelsitz. Die Wellenscheibe dreht mit der Base und wird durch deren Zentrierbund ausgerichtet. Die Laufbahnen weisen zu den Wälzkörpern. Scheiben und Käfig nach ihrer tatsächlichen Geometrie und Herstellerkennzeichnung zuordnen; nicht allein nach ähnlichem Aussehen vertauschen.

Das 51105 trägt die axiale Rotorlast. Beim Fügen ausschließlich auf die einzusetzende Scheibe drücken und keine Kraft durch Wälzkörper leiten. Das Lager nicht durch Verspannen der Druckteile als Passungswerkzeug missbrauchen.

## 608 Passung und Orientierung

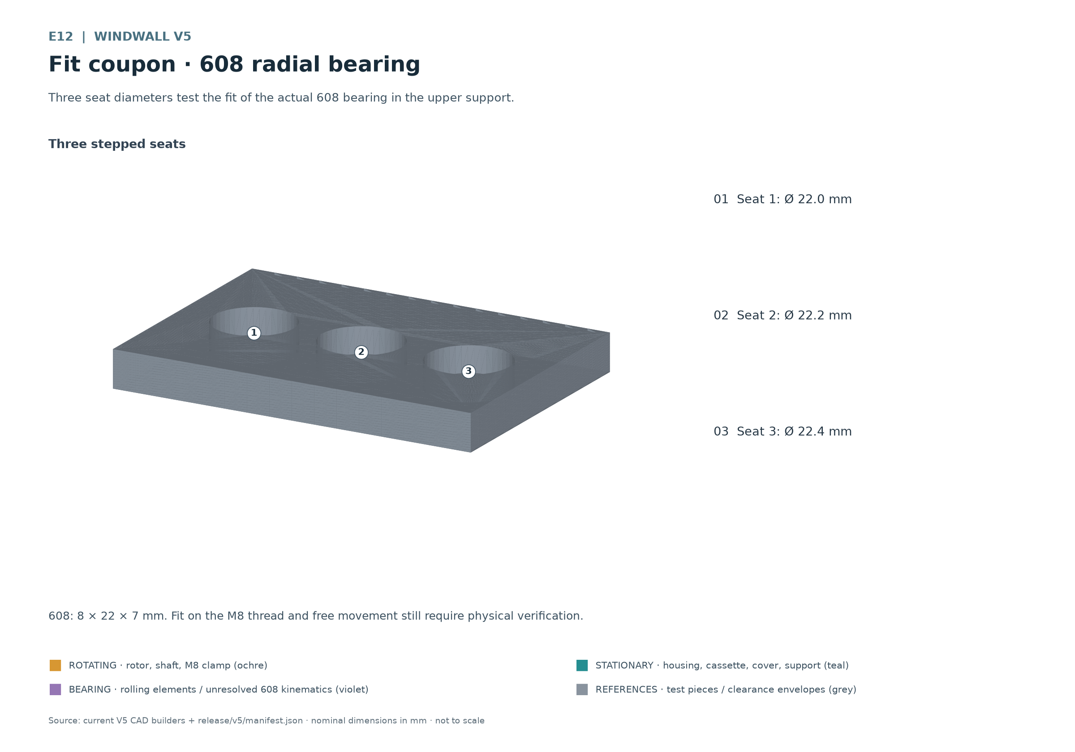
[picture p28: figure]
E12. Drei Sitzdurchmesser prüfen die Passung des realen 608-Lagers für den oberen Halter. 608: 8 × 22 × 7 mm. Passung auf M8-Gewinde und freie Bewegung bleiben praktisch zu prüfen. Sitz 1: Ø 22,0 mm Sitz 2: Ø 22,2 mm Sitz 3: Ø 22,4 mm

E12 Drei Sitzdurchmesser prüfen die Passung des realen 608-Lagers für den oberen Halter.

608: 8 × 22 × 7 mm. Der Außenring sitzt im stationären oberen Halter, der Innenring führt die rotierende M8-Welle. Wälzkörper bewegen sich zwischen den Ringen. Die violette CAD-Hülle löst diese innere Kinematik nicht auf.

Eine M8-Gewindestange ist kein geschliffener Lagerzapfen. Passe eine lokale Lauffläche nur nach Messung und kontrollierter Bearbeitung an; Durchmesser, Rundlauf, Restquerschnitt und sicheren Innenringsitz erneut prüfen. Eine gedruckte Führungshülse ist nicht vorgesehen. Der 608-Punkt führt hauptsächlich radial; vermeide eine ungewollte zweite axiale Verspannung.

# 6 Magnete und Testspule vorbereiten

Miss Magnetdurchmesser und Dicke einschließlich Beschichtung. Die Taschen sind 11 × 2 mm als Durchmesser und Tiefe; sie sind keine bestätigte Klemmung für einen Magneten mit 10 × 2 mm Projektmaß. Teste Klebstoff, Beschichtung und Rückhaltung am Coupon. Klebstoffhöhe darf den Luftspalt nicht unbemerkt verringern.

1. Polflächen markieren. Einen Referenzmagneten benutzen und dieselbe Polfläche aller Magnete markieren. Pole vor dem Einsetzen erneut prüfen. Schutzbrille tragen und Magnete mit nichtmagnetischen Abstandshaltern getrennt halten.

2. Oberen Ring bestücken. Zur Spule zeigen die Pole abwechselnd N S N S rund um den Ring. Eine feste Taschenposition als Start markieren und die gesamte Polfolge protokollieren.

3. Unteren Ring zuordnen. An gleicher Winkelposition steht dem oberen N-Pol unten ein S-Pol gegenüber; beim nächsten Paar entsprechend umgekehrt. Die zur Spule gerichteten Flächen sind entscheidend. Auf der Werkbank gleich orientierte Scheiben können nach dem Umdrehen eine andere Zuordnung zeigen.

4. Rückhaltung prüfen. Magnete vollständig setzen und Befestigung nach dem konkreten Produkt aushärten lassen. Beide Ringe zuerst einzeln prüfen. Die Magnetrückhaltung ist vor jeder Drehprobe ein eigenständiges offenes Prüfkriterium.

## Serpentinenwicklung als Versuch

Lege den isolierten Draht als durchgehende Serpentine um die 18 abgerundeten Führungskörper der stationären Kassette. Führe ihn abwechselnd an der Innen- und Außenseite der nächsten Führung vorbei. Markiere Anfang A, Ende B und den Weg einer vollständigen Wiederholung. Für diese Versuchsreihe zählt eine vollständige Runde um alle 18 Führungen als eine Windung. Alle Testspulen müssen denselben Verlauf und dieselbe Wickelrichtung verwenden.

Prüfe den Verlauf zuerst mit wenigen Wiederholungen bei Handdrehung: Die Beiträge aufeinanderfolgender aktiver Abschnitte sollen sich addieren. Veränderte Polfolge, umgekehrte Teilstücke oder andere Drahtwege können Spannung aufheben. Dokumentiere den realen Verlauf mit Foto oder Skizze; die Kassette legt keine abschließend geprüfte elektrische Wicklung fest.

Draht | Windungen | Vergleich und Messung
0,18 mm, real messen | 20 | Widerstand, Bauhöhe, Leerlaufspannung und Lastmessung bei gleicher Drehzahl
0,18 mm, real messen | 40 | Gleicher Verlauf und gleiche Wickelrichtung wie bei 20
0,18 mm, real messen | 80 | Nur einsetzen, wenn die reale Wicklung in den geprüften Raum passt

Für jeden später gemessenen Drahtdurchmesser die vollständige Matrix 20, 40 und 80 wiederholen. Leiterdurchmesser und Außendurchmesser mit Lack unterscheiden. Es gibt keine endgültige Windungszahl und keine zugesicherte Leistung. Den verfügbaren Wickelraum nicht mit maximal zulässiger Wärmeentwicklung verwechseln.

Anschlussenden außerhalb aktiver Laufspalte halten. Lötstellen isolieren, die Litzen mechanisch entlasten und Durchgang sowie Isolation zum übrigen Aufbau prüfen. Vor dauerhaftem Verguss zuerst eine entnehmbare Testspule messen; Verguss kann Wärmeabfuhr, Reparatur, Höhe und Passung verändern.

# 7 Generator montieren

Arbeite bei gesichertem Stillstand mit einer Montagehilfe, die die Anziehung der Magnetringe kontrolliert. Der Gehäusetopf öffnet nach oben. Prüfe vorab Muttertaschen, Schulter, Schlüssel und Kabelweg. Setze die vier gefangenen M4-Muttern vor dem Verschließen vollständig ein.

1. Unteren Magnetrotor einsetzen. M8-Drehmomentmutter von unten in die offene Tasche setzen. Unteren Rotor mit Welle und integrierter Distanzhülse in den Topf einsetzen, Magnetflächen nach oben. Der Magnetträger bleibt im Gehäuse; die Hülse läuft frei durch die stationäre Mitte. Mutter und Wellenende dürfen den geschlossenen Boden nicht berühren.

2. Spulenkassette einsetzen. Die Wicklung zuvor auf Passung und Isolation prüfen. Kassette über die Welle absenken, auf der Gehäuseschulter absetzen und den einzelnen Schlüssel in die Verdrehsicherung führen. Die seitlichen Kabelöffnungen müssen fluchten.

3. Stationären Deckel montieren. Kabel aus dem seitlichen Ausgang führen und entlasten. Deckel plan aufsetzen und die vier M4-Schrauben in gefangene Muttern einschrauben. Gleichmäßig und schrittweise über Kreuz anziehen; bei Spalt oder Verformung stoppen. Die getrennten äußeren Rahmenbohrungen bleiben dabei unberührt. Für PLA liegt kein geprüftes Anziehdrehmoment vor.

4. 51105 einsetzen. Stationäre Gehäusescheibe auf den Deckelbund setzen, dann Wälzkörper und rotierende Wellenscheibe mit einander zugewandten Laufbahnen einsetzen. Lager sauber halten; den Zentrierbund der Base mit der realen Wellenscheibe abgleichen.

5. Base aufsetzen. Obere Drehmomentmutter einsetzen, Base auf Welle und Lager absenken. Ihre Magnetflächen zeigen zur Spule nach unten. Die Base-Schulter trägt auf der rotierenden Wellenscheibe. Magnetanziehung durch die Montagehilfe begrenzen und Finger aus dem Spalt halten.

6. Laufspalte messen. Welle von Hand vollständig drehen. Jeden Winkel auf Kontakt, Kabelzug und sichtbaren Schlag prüfen. Tatsächliche Magnetflächen, Wicklung und Klebstoff bestimmen die Freigänge. Erst nach erfolgreicher Prüfung mit dem Rotorstapel fortfahren.

## Unterer Rotor im Gehäuse

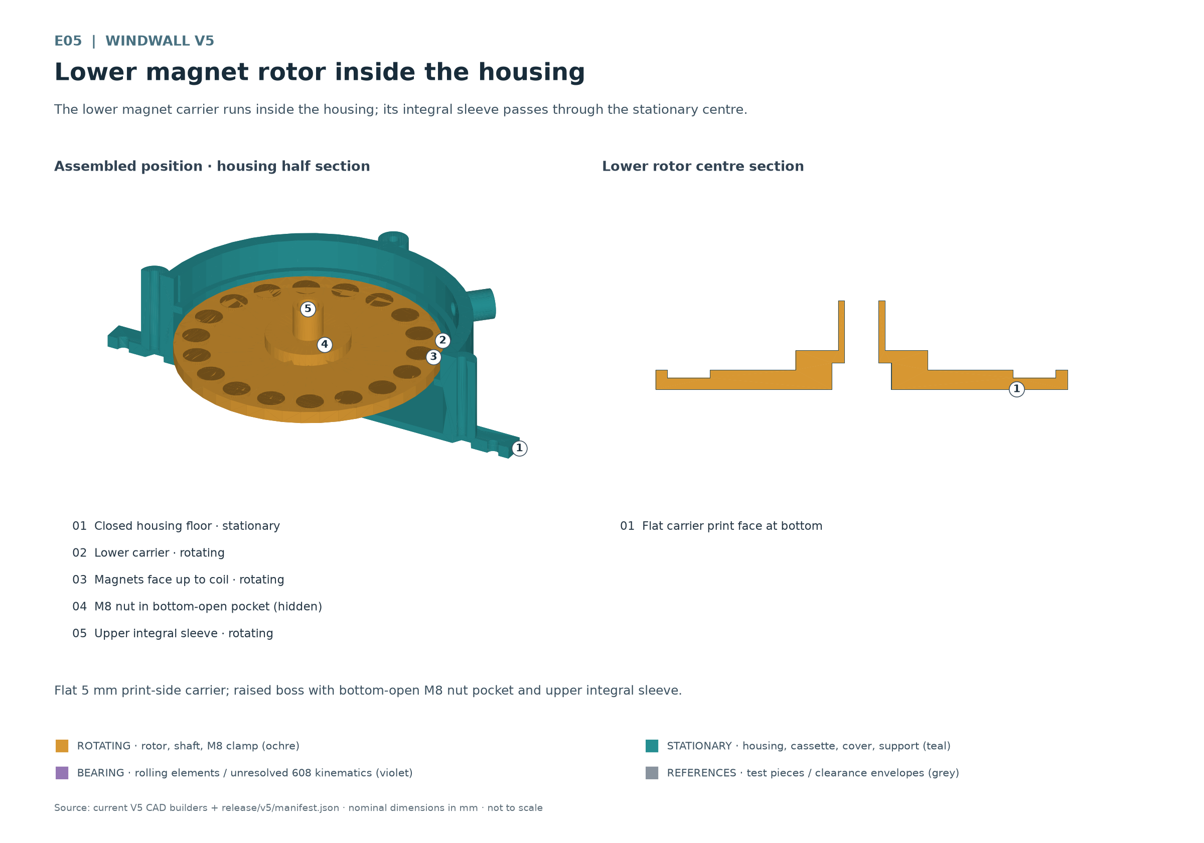
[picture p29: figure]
E05. Der untere Magnetträger läuft innerhalb des Gehäuses; seine integrierte Hülse führt durch die stationäre Mitte. Plane 5 mm dicke Druckfläche; erhöhter Mittelbereich mit nach unten offener M8-Muttertasche und oberer integrierter Hülse. Geschlossener Gehäuseboden stationär. Unterer Träger rotie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

E05 Der untere Magnetträger läuft innerhalb des Gehäuses; seine integrierte Hülse führt durch die stationäre Mitte.

Die plane 5 mm dicke Trägerfläche liegt beim Druck auf dem Bett. Der erhöhte Mittelbereich enthält die nach unten offene M8-Muttertasche zur Drehmomentübertragung. Die integrierte Distanzhülse liegt oben und dreht mit dem unteren Magnetrotor; die stationäre Spule darf sie nicht berühren. Die CAD-Hülse misst 12 × 17,85 mm als Außendurchmesser und Höhe, mit 8,8 mm M8-Durchgang. Reale Klemmung und Bodenabstand trocken prüfen. Steifigkeit, Brückendruck, Maßpassung, Außenbetrieb und angetriebener Betrieb bleiben physisch unvalidiert.

## Generator in Einbaureihenfolge

E06. Kassette, Deckel und Base sind angehoben; der untere Magnetrotor bleibt im aufgeschnittenen Gehäuse. Unterer Rotor unter der stationären Wicklung. Die vollständigen V5.2-Base-Blätter sind dargestellt. Base mit oberem Magnetträger · rotierend Deckel und 51105-Aufnahme · stationär Spulenkassett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

E06 Kassette, Deckel und Base sind angehoben; der untere Magnetrotor bleibt im aufgeschnittenen Gehäuse.

Die angehobenen Teile zeigen den Zugang von oben. Die Wicklung bleibt zwischen den beiden rotierenden Magnetträgern stationär. Den unteren Magnetrotor vor Kassette und Deckel einsetzen; nach dem Verschließen ist der Topfboden kein Montagezugang.

## Axiallager und Lastpfad

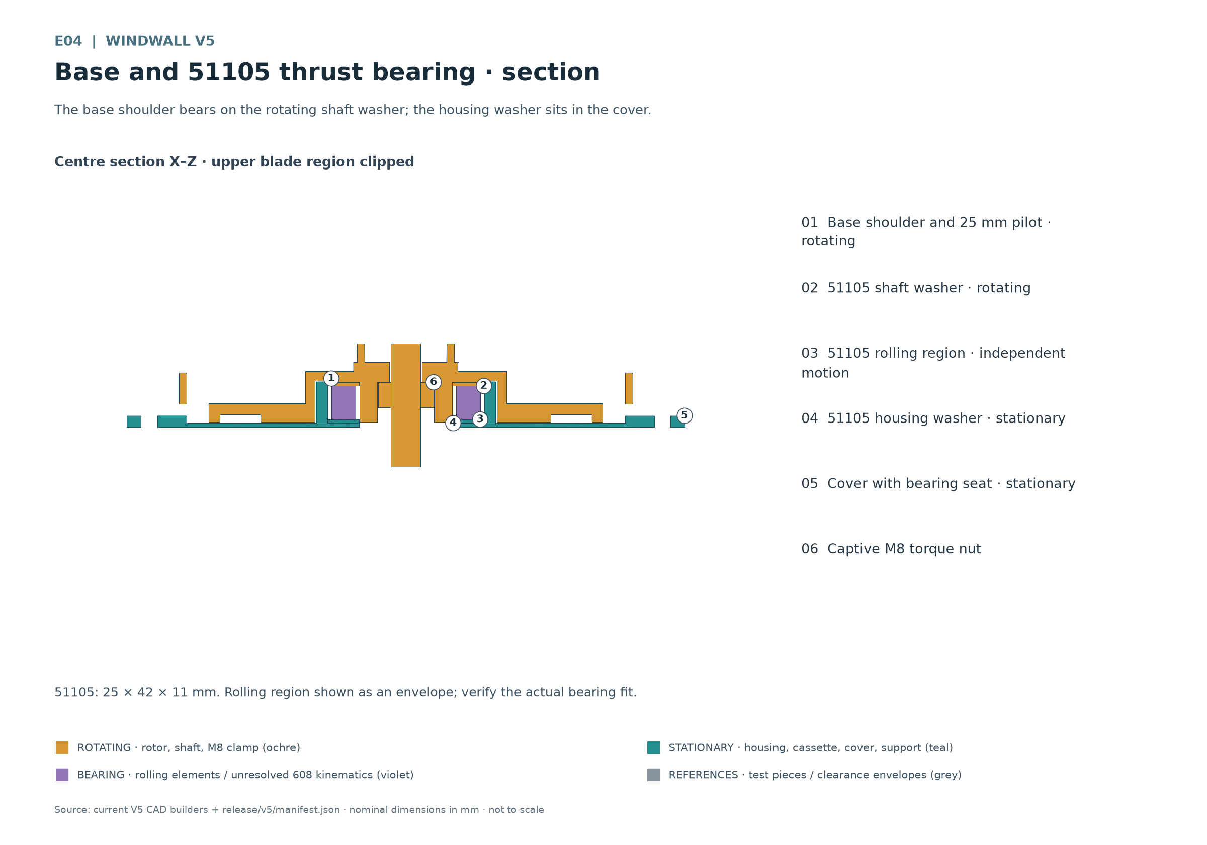
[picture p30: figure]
E04. Die Base-Schulter trägt auf der rotierenden Wellenscheibe; die Gehäusescheibe sitzt im Deckel. 51105: 25 × 42 × 11 mm. Wälzbereich als Hülle; tatsächliche Lagerpassung prüfen. Base-Schulter und 25-mm-Pilot · rotierend 51105-Wellenscheibe · rotierend 51105-Wälzbereich · eigene Bewegung 51105-G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

E04 Die Base-Schulter trägt auf der rotierenden Wellenscheibe; die Gehäusescheibe sitzt im Deckel.

Die Rotorlast läuft von der Base-Schulter über die Wellenscheibe, Wälzkörper und Gehäusescheibe in den stationären Deckel und weiter über das Gehäuse zum unteren Rahmen. Die M8-Klemmung verbindet rotierende Teile; sie darf den stationären Deckel oder die Wicklung nicht einklemmen.

## Beide Luftspalte kontrollieren

E07. Zwei rotierende Magnetträger umschließen die stationäre Wicklung; der untere Rotor sitzt im Gehäuse. Magnetfläche zur aktiven Wicklung: oben 1,5 mm und unten 1,5 mm einschließlich Kunststoff. Mechanisch: Magnet zu Deckel 0,35 mm; Magnet zu Kassettenboden 0,50 mm. Base und oberer Magnetträger 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

E07 Zwei rotierende Magnetträger umschließen die stationäre Wicklung; der untere Rotor sitzt im Gehäuse.

Oben sind 1,5 mm und unten 1,5 mm nominal von der Magnetfläche zur aktiven Wicklungsfläche vorgesehen. Beide magnetischen Abstände schließen den dazwischenliegenden Kunststoff ein: oben die Deckelmembran, unten den Kassettenboden. Sie gelten nur, wenn Magnete bündig oder tiefer in ihren Taschen sitzen. Überstand, Klebstoff, Wicklungshöhe, axialer Versatz und Rundlauf können den tatsächlichen kleinsten Abstand verringern.

Die mechanischen Freigänge sind kleiner: oben 0,35 mm zwischen Magnetfläche und Deckelmembran, unten 0,50 mm zwischen Magnetfläche und Kassettenboden. Die Membran und der Kassettenboden sind jeweils 1,00 mm dick. Zwischen Kassettenoberkante und Deckelunterseite bleiben 0,15 mm zur axialen Rückhaltung. Magnetische Abstände und mechanische Freigänge getrennt prüfen.

Miss über eine vollständige Handumdrehung und prüfe auch vorhandenes axiales Spiel. Ein berührungsfreier CAD-Zustand bestätigt keine Reserve unter Last. Bei Schleifen weder einschleifen noch mit höherer Drehzahl freifahren; Ursache lokalisieren und den Aufbau korrigieren.

## Kassette und Deckel sichern

E08. Die Kassette sitzt auf der Gehäuseschulter; der Deckel begrenzt den Hub nach oben. Der einzelne Schlüssel bei −X sperrt die Verdrehung. Passung am Segment-Coupon prüfen. Deckel hält die Kassette axial zurück Kassette mit 18 abgerundeten Wicklungsführungen Gehäuseschulter und passende Schlüsse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

E08 Die Kassette sitzt auf der Gehäuseschulter; der Deckel begrenzt den Hub nach oben.

Die Gehäuseschulter hält die Kassette nach unten, der Passring zentriert radial und der Schlüssel verhindert Verdrehung. Der verschraubte Deckel begrenzt den Weg nach oben. Alle vier Funktionen müssen bei der Trockenmontage vorhanden sein; ein nur lose eingelegter Wicklungsträger ist nicht betriebsbereit.

## Deckelschrauben kontrollieren

E09. Vier M4-Schrauben befestigen den stationären Deckel; getrennte äußere Bohrungen befestigen das Gehäuse am Rahmen. Verstärkung und Rahmenbohrung liegen auf derselben radialen Achse. Zugang von oben; Werkzeugfreiraum prüfen. 4 × M4-Schraube · stationär Deckel mit vier Durchgangsbohrungen Verstä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

E09 Vier M4-Schrauben befestigen den stationären Deckel; getrennte äußere Bohrungen befestigen das Gehäuse am Rahmen.

Vier M4-Schrauben und vier gefangene Sechskantmuttern verbinden Deckel und Gehäuse. Sie liegen auf denselben radialen Achsen wie die vier getrennten Rahmenbohrungen; die durchgehenden Bosse verstärken dabei die unteren Laschen. Der Schraubenzugang erfolgt von oben. Nach dem Anziehen muss der Deckel plan sitzen und die Welle weiterhin frei laufen.

## Seitliches Kabel herausführen

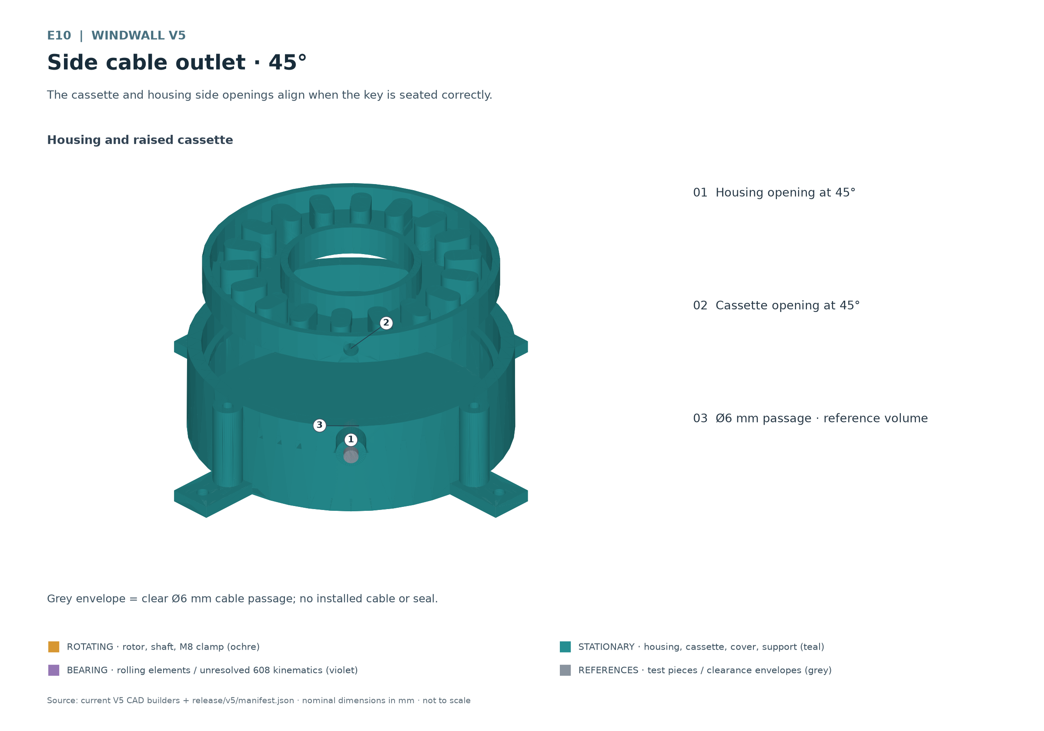
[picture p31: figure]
E10. Die seitlichen Öffnungen von Kassette und Gehäuse fluchten bei korrekt eingesetztem Schlüssel. Graue Hülle ist der freie Kabeldurchgang Ø6 mm; kein montiertes Kabel und keine Abdichtung. Gehäuseöffnung bei 45 Grad Kassettenöffnung bei 45 Grad Ø6-mm-Durchgang · Referenzvolumen

E10 Die seitlichen Öffnungen von Kassette und Gehäuse fluchten bei korrekt eingesetztem Schlüssel.

Führe die isolierten Anschlusslitzen durch die fluchtenden seitlichen Öffnungen. Die Leitung braucht eine reale Zugentlastung und Kantenschutz; die graue Hülle zeigt lediglich den Kabeldurchgang. Sie ist keine montierte Durchführung und keine Abdichtung. Der Ausgang ist nicht wasserdicht. Halte das freie Kabel vollständig außerhalb der drehenden Teile.

# 8 Rotorstapel montieren

E01. Ein Base-Modul, fünf gleiche Standard-Module und ein Top-Modul bilden den Rotor. Einfügepositionen auseinandergezogen; dauerhafte Rastung nach dem Verriegeln. Stufe 1: Base-Modul · rotierend Stufe 2: Standard-Modul · rotierend Stufe 3: Standard-Modul · rotierend Stufe 4: Standard-Modul · roti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

E01 Ein Base-Modul, fünf gleiche Standard-Module und ein Top-Modul bilden den Rotor.

Auf die bereits gelagerte Base folgen fünf identische Standardmodule und abschließend das Topmodul. Die M8-Welle läuft durch die freien Mitten und die kurzen Führungsbereiche. Halte den Stapel während der Montage gegen Kippen gesichert.

1. Einfügeposition ausrichten. Die Bajonettklauen und Einführfenster jeder neuen Stufe ausrichten. Die Stufen haben glatte bündige Blattenden. Das zentrale Bajonett ist die einzige formschlüssige Drehmomentschnittstelle.

2. Stufe verriegeln. Von oben gesehen gegen den Uhrzeigersinn bis zum vorgesehenen Anschlag verriegeln. Die dauerhafte Rastung muss greifen. Kein übermäßiges Drehmoment und keinen Hammer verwenden; bei klemmender Verbindung die Coupons und Passflächen prüfen.

3. Naht prüfen. Nach dem Verriegeln den bündigen Blattkontakt, den Sitz aller Klauen, die Rastung und das axiale Spiel jeder Verbindung kontrollieren. Ein sichtbarer Versatz oder ein beschädigter Rastzahn ist ein Abbruchgrund. Den nächsten Abschnitt erst nach dieser Kontrolle aufsetzen.

4. Obere Klemmung schließen. Scheibe direkt auf die ebene obere Top-Platte legen und die M8-Mutter montieren. Klemmung vor der Montage des oberen Lagerhalters einstellen. Der reale Lagerlauf und die Blattverbindungen dürfen beim Anziehen nicht verspannt werden.

## Drei Modultypen unterscheiden

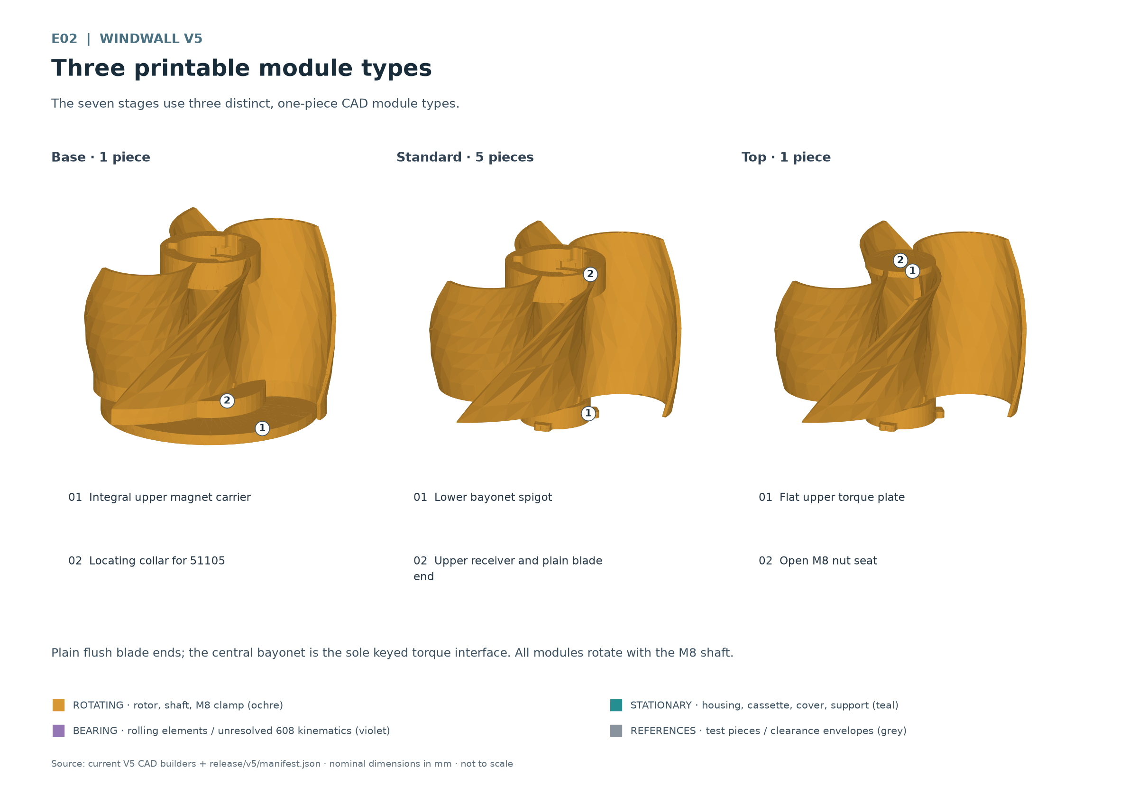
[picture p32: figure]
E02. Die sieben Stufen bestehen aus drei unterschiedlichen, einteiligen CAD-Modultypen. Glatte bündige Blattenden; das zentrale Bajonett ist die einzige formschlüssige Drehmomentschnittstelle. Alle Module drehen mit der M8-Welle. Oberer Magnetträger integriert. Zentrierbund für 51105. Unterer Bajo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

E02 Die sieben Stufen bestehen aus drei unterschiedlichen, einteiligen CAD-Modultypen.

Die Base besitzt den oberen Magnetträger und den 51105-Zentrierbund. Das Standardmodul trägt unten das männliche und oben das weibliche Verbindungsteil. Das Topmodul beendet den Stapel mit einer ebenen oberen Kraftplatte für Scheibe und M8-Klemmung. Alle drei Typen sind jeweils ein Druckkörper.

## Bajonett und Blattnaht kontrollieren

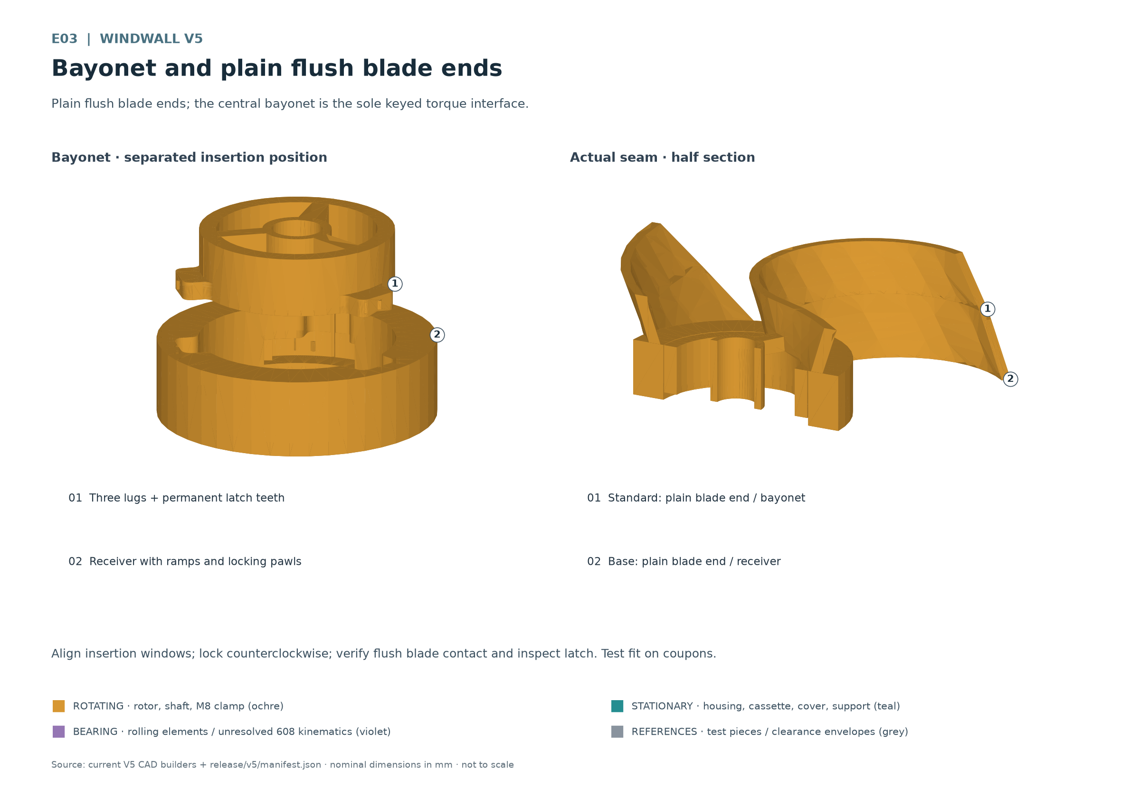
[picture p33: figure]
E03. Glatte bündige Blattenden; das zentrale Bajonett ist die einzige formschlüssige Drehmomentschnittstelle. Einführfenster ausrichten, gegen den Uhrzeigersinn verriegeln, bündigen Blattkontakt und Rastung prüfen. Passung zuerst am Coupon testen. Drei Klauen und dauerhafte Rastzähne. Aufnahme mit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

E03 Glatte bündige Blattenden; das zentrale Bajonett ist die einzige formschlüssige Drehmomentschnittstelle.

Die Rastung ist für eine dauerhafte Verbindung vorgesehen. Plane den Rotorstapel als Einheit; ein Spulenwechsel soll keine Trennung der sechs Stufenverbindungen erfordern. Die reale elastische Einfügung und Kraftübertragung bleiben durch Coupons und einen Aufbau aus zwei Stufen zu bestätigen.

# 9 Am Holzrahmen montieren

Die M8-Klemmung am Topmodul zuerst fertig einstellen und Werkzeugzugang prüfen. Danach die verlängerte M8-Welle durch den oberen Lagerpunkt führen. Rahmenabstand und Stangenlänge ergeben sich aus der realen Trockenmontage einschließlich Lager, Muttern, Spiel und notwendigen Gewindeeingriffen.

1. Unteren Rahmen vorbereiten. Auflage eben und tragfähig ausführen. Das Gehäuse steht mit vier Bodenlaschen auf dem Holz. Die vier unteren Holzschrauben werden von oben nach unten außerhalb des rotierenden Innenraums eingebracht. Vorbohrung, Randabstand und Schraubenlänge am vorhandenen Holz festlegen.

2. Halter montieren. 608 von oben in den offenen Lagersitz des stationären Halters setzen. Halter mit vier Holzschrauben von unten nach oben gegen den oberen Holzrahmen montieren. Die untere Schulter hält das Lager nach unten; das Holz schließt den Sitz und hält es nach oben zurück.

3. Welle ausrichten. Oberen Halter zur unteren Lagerachse ausrichten, bevor die vier Schrauben endgültig gesetzt werden. Die Welle muss ohne seitlichen Zwang durch den 608 laufen. Abstand zu Topmodul, Scheibe und Mutter über eine volle Handumdrehung prüfen.

4. Wellenende prüfen. Die verlängerte Welle muss den Innenring über dessen ganze Breite führen und auch bei axialem Spiel sicher eingreifen. Freiraum am oberen Holz für Wellenende und Bewegung vorsehen. Überstand nicht gegen den Holzrahmen verspannen.

E13. Der stationäre Halter wird von unten an den Holzrahmen geschraubt; das Holz schließt den Lagersitz. M8-Klemmung zuerst anziehen. Vier Holzschrauben 4 × 40 mm sind ungeprüfte Nennhüllen. Vorhandener Holzrahmen · stationär 608-Lager in nach oben offenem Sitz Halter 80 × 50 × 12 mm · stationär 4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

E13 Der stationäre Halter wird von unten an den Holzrahmen geschraubt; das Holz schließt den Lagersitz.

## Befestigung zwischen den Holzriegeln

E14. Zwischen zwei Holzriegeln: Gehäuse von oben befestigt, oberer 608-Halter von unten angeschraubt. Holz und Holzschrauben sind Referenzen und keine Druckteile. Querschnitte und Befestigung vor Ort auslegen; keine Lastfreigabe. Oberer Holzriegel · Referenz, nicht drucken 608-Halter · 4 Holzschra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

E14 Zwischen zwei Holzriegeln: Gehäuse von oben befestigt, oberer 608-Halter von unten angeschraubt.

Die Zeichnung verwendet unten 4 × 30 mm und oben 4 × 40 mm als ungeprüfte Schraubenhüllen. Holzquerschnitte sind Beispiele. Sie sind keine Freigabe für den vorhandenen Zaun oder eine bestimmte Windlast. Die Befestigung und das Holz vor Ort auslegen und prüfen.

Der obere Lagerhalter führt radial. Die vorgesehene axiale Lastabstützung erfolgt am unteren 51105. Nach dem Verschrauben nochmals Handlauf, Lagergeräusch, kleinsten Luftspalt und Kabelabstand kontrollieren. Erst danach den geschützten Prüfstand für Messungen vorbereiten.

# 10 Spulen messen und vergleichen

Vergleiche jede Spule bei denselben protokollierten Drehzahlen und derselben Last. Die drei Windungszahlen sind eine experimentelle Matrix. Ein höherer Leerlaufwert allein zeigt nicht, welche Spule unter Last brauchbar arbeitet.

1. Spule im Stillstand prüfen. Drahtdurchmesser, Windungszahl, Verlauf, Wicklungshöhe, Widerstand und Umgebungstemperatur notieren. Leiterenden eindeutig A und B markieren. Isolation zu Welle und Magnetträgern kontrollieren.

2. Leerlauf messen. Im geschützten Aufbau langsam und kontrolliert antreiben. Drehzahl und AC-Leerlaufspannung gleichzeitig erfassen. Die Bandbreite des Messgeräts muss zur tatsächlichen Signalform passen. Einen offenen Messkontakt nicht als geringe Generatorleistung deuten.

3. Definierte Last anschließen. Nur eine zuvor passend bemessene Last verwenden. Bei gleicher Drehzahl Spannung, Strom und Temperatur erfassen. Lastwert, Messdauer, Umgebung und Kabelzustand festhalten. Bei heißer Wicklung, Geruch, Vibration oder Kontakt sofort stillsetzen.

4. Ergebnisse vergleichen. Für rein ohmsche Lasten kann die mittlere Leistung aus geeignet gemessenen Effektivwerten bestimmt werden. Bei Gleichrichter oder gepulstem Strom passende DC- oder echte Leistungsmessung verwenden; AC-Werte nicht ungeprüft multiplizieren.

Messgröße | Für jeden Versuch dokumentieren
Identität | Spulenkennung, Material, realer Drahtdurchmesser, Lackdurchmesser, Windungen und Drahtweg
Mechanik | Magnetpolfolge, Magnetüberstand, Spulenhöhe, kleinster oberer und unterer Luftspalt
Elektrik | Widerstand kalt, Drehzahl, AC-Leerlaufspannung, Lastwert, Lastspannung und Laststrom
Wärme und Zeit | Umgebungstemperatur, Spulentemperatur, Messdauer und Temperaturverlauf
Beobachtung | Anlaufverhalten, Geräusche, Vibration, Schleifen, lockere Teile und Abbruchgrund

Eine Windungsskalierung aus der Leerlaufspannung ist höchstens eine erste Näherung bei unverändertem Magnetfeld, Verlauf und gleicher Drehzahl. Widerstand, Kupferfüllung, Bauraum und Erwärmung ändern sich mit. Jede abgeleitete Wicklung muss erneut als reale Spule geprüft werden.

# 11 Geschützt in Betrieb nehmen

Eine erste Drehprobe setzt bestätigte Magnetrückhaltung, feste Rahmenbefestigung, geschlossene Kassettensicherung und einen freien Handlauf voraus. Abschirmung gegen herausgeschleuderte Teile und eine sichere Stillsetzmöglichkeit vorsehen. Personen, Haare, Kleidung und lose Gegenstände von der Rotation fernhalten.

1. Stillstand kontrollieren. Schraubenmarkierungen, Rastverbindungen, Lager, Kabel und beide Luftspalte prüfen. Fremdkörper entfernen. Elektrische Messleitungen vor der Bewegung befestigen.

2. Langsam beginnen. Drehung unter kontrollierten Bedingungen stufenweise erhöhen und nach jeder Änderung beobachten. Es gibt keine freigegebene Höchstdrehzahl. Keine Wind-, Sturm- oder Überdrehzahlprobe aus dieser Anleitung ableiten.

3. Bei Abweichungen stoppen. Schleifen, Risse, Magnetbewegung, auffällige Lagergeräusche, Erwärmung oder lockere Befestigung erfordern Stillstand und Ursachensuche. Erst nach Korrektur und erneuter Handprüfung fortfahren.

## Ladeelektronik erst nach Messungen auswählen

Den Generator nicht direkt an einen 48-V-Bleiakku anschließen, auch nicht versuchsweise. Nennspannung und Leerlaufmessung reichen für die Auswahl eines Ladesystems nicht aus. Batterietyp und Ladeprofil müssen zum konkreten Hersteller passen.

Ein späterer Anschlussplan muss Gleichrichtung, geeignete Laderegelung, Rückstromsperre, Leitungs- und Kurzschlussschutz, sichere Trennung und Energieabfuhr bei fehlender Last abdecken. Bauteile nach gemessener Spannung, Strom, Wärme und Fehlerfällen auswählen. Eine gegebenenfalls erforderliche Ersatzlast muss thermisch und elektrisch ausgelegt sein. Diese Anleitung enthält dafür keinen freigegebenen Schaltplan.

Die Entwicklung bleibt bis dahin am definierten Messaufbau. Freier Lauf im Wind, Ladebetrieb, Wassereintritt, UV, Frost, Dauerlast und unbeaufsichtigter Betrieb sind nicht validiert.

# 12 Wartung und Fehlersuche

## Spulenkassette entnehmen

1. Stillsetzen und abstützen. Rotor mechanisch gegen Bewegung sichern und elektrische Leitungen spannungsfrei trennen. Den Rotorstapel als Einheit abstützen. Magnetkräfte und Gewicht beim Ausbau kontrollieren.

2. Oberen Zugang freimachen. Oberen Lagerhalter bei gesichertem Stapel lösen und Welle freiführen. Die untere rotierende Baugruppe mit einer Montagehilfe halten. Base und oberen Rotorstrang soweit entlasten und abheben, dass das 51105 und der Deckel zugänglich werden. Erforderliche M8-Verbindungen im Stillstand lösen, ohne die Stufenrastungen zu trennen.

3. Deckel abnehmen. Lagerteile nach ihrer Orientierung getrennt ablegen. Vier Deckelschrauben lösen, Deckel abheben und Kabelzugentlastung freigeben. Die getrennten Rahmenbefestigungen bleiben montiert; der untere Magnetrotor bleibt gesichert im Gehäuse.

4. Kassette nach oben herausheben. Kabel vorsichtig nachführen, Schlüssel aus der Nut heben und Kassette nach oben über die freigegebene Welle entnehmen. Nicht am Draht ziehen. Der reale Serviceweg ist bei der Trockenmontage zu prüfen.

5. Wieder montieren. Nach Kapitel 7 in Reihenfolge montieren, oberen Halter wieder ausrichten und alle Freigänge erneut messen. Ein Spulenwechsel kann Wicklungshöhe und Luftspalte verändern.

Vor jeder Versuchssitzung und nach Transport, Materialwechsel oder Spulenwechsel Risse, Verzug, Spiel, Schraubenmarkierungen, Magnetbefestigung und Isolation prüfen. Verschleiß oder gelöste Teile ersetzen und die betroffene Passprüfung wiederholen.

Beobachtung | Prüfung bei Stillstand
Rotor schleift | Magnetüberstand, Spulenhöhe, beide Luftspalte, integrierte Rotorhülse und axialen Versatz messen.
Schwergängiges Lager | Scheibenorientierung, verkantete Sitze, obere Achsausrichtung und axiale Verspannung kontrollieren.
Kassette bewegt sich | Schulter, Schlüssel, Passring und plan sitzenden Deckel auf Druckfehler prüfen.
Geringe oder keine Spannung | Drehzahl, Drahtdurchgang, Lötstellen, Polfolge und additive Verschaltung des Serpentinenwegs prüfen.
Wicklung wird heiß | Laststrom, Wicklungswiderstand, Isolation und Wärmeabfuhr prüfen; keine weitere Drehprobe bis zur Klärung.
Vibration oder lockere Muttern | Rundlauf, Magnetverteilung, Rahmensteifigkeit und M8-Klemmung prüfen; nicht durch höhere Drehzahl übergehen.

# 13 Versuche dokumentieren

Führe für jede Bauvariante ein eigenes Protokoll mit Datum, Material, Druckprofil und verwendeten Release-Dateien. Bewahre Fotos der Polfolge, der Drahtführung und der realen Montage auf. Ein erfolgreicher Einzelversuch ist keine Dauer- oder Außenfreigabe.

Prüfbereich | Erforderlicher Nachweis
Druck und Passungen | Couponvariante, reale Maße, Fügekräfte, Rissfreiheit und Materialprofil
Mechanische Montage | Muttereingriff, Lagerorientierung, Wellenlänge, Rahmenbefestigung und freie Handumdrehung
Generator | Magnetbefestigung, Polfolge, tatsächlicher Überstand und kleinste Luftspalte
Spule | Matrix aus Kapitel 6 und Messdaten aus Kapitel 10 einschließlich Temperatur
Weiterer Versuch | Begründung, offene Punkte, Abbruchkriterien und notwendige Korrekturen

## Zeichnungen finden

ID | Datei
E01 | E01-rotorstapel.png
E02 | E02-modultypen.png
E03 | E03-bajonett-blattnaht.png
E04 | E04-base-51105-schnitt.png
E05 | E05-unterer-magnetrotor.png
E06 | E06-generator-explosion.png
E07 | E07-generator-schnitt.png
E08 | E08-kassettenrueckhaltung.png
E09 | E09-deckelverschraubung.png
E10 | E10-seitlicher-kabelausgang.png
E11 | E11-51105-passungsprobe.png
E12 | E12-608-passungsprobe.png
E13 | E13-oberer-halter.png
E14 | E14-zaunmontage.png
E15 | E15-gesamtbaugruppe.png

## Projektstand und Aussagegrenzen

Release-Inventar und Maße: release/v5/manifest.json. Zeichnungen und Bildbeschreibungen: release/v5/drawings/figures.json. Die Anleitung gilt für den V5-Aufbau mit stationärem Generatorgehäuse und oberem Lagerhalter.

Physische Passung, Lagerhalt, Magnetrückhaltung, elektrische Funktion, Festigkeit, Dauerfestigkeit, Überdrehzahl und Wetterverhalten bleiben nachzuweisen. CAD-Freigänge und geschlossene STL-Körper ersetzen diese Versuche nicht. Erst bestätigte Messungen erlauben den nächsten Entwicklungsschritt.

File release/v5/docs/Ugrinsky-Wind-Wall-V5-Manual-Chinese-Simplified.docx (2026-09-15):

# Ugrinsky Wind Wall V5 装配手册

PLA 原型的装配与线圈试验

# 1 用途与限制

本手册介绍配合试样、打印、七级转子装配以及可相互比较的线圈试验。首先搭建带防护的车间试验装置。只有实际测量之后，才能选择绕组、磁铁固定方式和充电电子设备。

原型状态。 V5 尚未经过实物验证。CAD 检查只能确认几何属性，不能证明安全转速、疲劳寿命、输出功率或无人值守户外运行的适用性。这些配合并非已认可的过盈配合。侧面电缆出口和外壳不防水。

电气限制。 不得将发电机直接连接到 48-V 铅酸蓄电池。初期试验只能使用带防护的测量装置，并连接参数明确且额定能力合适的负载。

未经验证的概念图：现代住宅与花园的写实宽阔景观，其中一个可能的围栏单元清晰展示十个细长的垂直乌格林斯基转子

概念图 一个可能用于花园的围栏单元，其中布置了十个乌格林斯基转子

特性 | V5 标称值
转子级数 | 7：1 个底部模块，5 个标准模块，1 个顶部模块
转子直径 | 122 mm
级间距与转子高度 | 70 × 490 mm
加长轴的包络尺寸 | 555.8 mm；不是最终切割尺寸
打印实体 | 8 种不同 STL 文件，共 12 件

## 理解整体装配

E15。七级转子和发电机安装在上下木横梁之间。木材与木螺钉：不要打印，现场设计。CAD V5；配合、电气及运行未经验证。上木横梁：不要打印。608 支架：4 个螺钉从下方安装。转子：1 个底部 + 5 个标准 + 1 个顶部模块。底部安装耳：4 个螺钉从上方安装。下木横梁：不要打印。上磁铁载盘：旋转。绕组与线圈盒：静止。下磁转子：旋转。外壳与盖板：静止。

E15 七级转子和发电机安装在上下木横梁之间。

赭色表示旋转部件。青绿色表示静止打印件。紫色表示轴承区域，其中滚动体与套圈的运动各不相同。灰色的木材、螺钉和间隙参考体不是打印件。

两个磁铁载盘随轴、M8 夹紧件和转子叠组一起旋转。线圈、线圈盒、外壳、盖板及上支架保持静止。下磁转子在外壳内部、静止线圈下方旋转。

查阅指南：第 2、3 章介绍打印件和外购五金；第 4、5 章介绍打印和配合试样；第 6 至 9 章介绍绕线和装配；第 10、11 章介绍测量和试运行；第 12、13 章介绍维护、故障排查及试验记录。

# 2 打印件与文件

数量对应一套完整转子，包括发电机外壳和上支架。上磁铁载盘集成在底部模块中。STL 文件位于 release/v5/stl/，对应 STEP 文件位于 release/v5/step/。

数量 | 打印件 | STL 文件 | STEP 文件
1 | 含上磁铁载盘的底部模块 | base_rotor_module.stl | base_rotor_module.step
5 | 标准模块 | standard_rotor_module.stl | standard_rotor_module.step
1 | 顶部模块 | top_rotor_module.stl | top_rotor_module.step
1 | 下磁转子 | lower_magnet_rotor.stl | lower_magnet_rotor.step
1 | 发电机外壳 | generator_housing.stl | generator_housing.step
1 | 线圈盒 | coil_cassette.stl | coil_cassette.step
1 | 静止盖板 | generator_cover.stl | generator_cover.step
1 | 上轴承支架 | top_support.stl | top_support.step

底部、标准、顶部模块和下磁转子属于旋转件。外壳、线圈盒、发电机盖板及上轴承支架属于静止件。发布的 STL 在打印平台上的 Z = 0 处落地；这不表示打印方向已经自动优化。

## 配合试样与装配体

首次配合检查时，以下每种试样各打印一次。材料、配置或配合尺寸变化后须重新打印。试样 STL 位于 release/v5/coupons/，对应 STEP 文件位于 release/v5/step/。

数量 | 试样 STL | 试样 STEP
1 | magnet_pocket_coupon.stl | magnet_pocket_coupon.step
1 | 51105_outer_seat_coupon.stl | 51105_outer_seat_coupon.step
1 | 25mm_pilot_coupon.stl | 25mm_pilot_coupon.step
1 | 608_seat_coupon.stl | 608_seat_coupon.step
1 | coil_cassette_segment_coupon.stl | coil_cassette_segment_coupon.step
1 | bayonet_male.stl | bayonet_male.step
1 | bayonet_female.stl | bayonet_female.step
1 | joint_male.stl | joint_male.step
1 | joint_female.stl | joint_female.step

## 用于检查的装配体

release/v5/assembly/rotor_locked.step

release/v5/assembly/generator.step

release/v5/assembly/fence_assembly.step

这些 STEP 装配体用于装配检查。fence_assembly.step 文件包含供上支架使用的加长轴。木材和外购件不会从装配体中导出为打印件。

# 3 外购零件与工具

本表描述计划中的原型。采购前必须与实物核对。标称包络不能证明螺纹啮合长度、螺钉头支承状态或承载能力。

数量 | 零件 | 尺寸与选择
1 | M8 螺纹杆 | 用于上部 608 的加长轴；试装后才能截短
3 | M8 螺母 | 两个形状啮合传递扭矩的螺母和一个顶部夹紧螺母
1 | 顶部 M8 垫圈 | 24 × 2 mm；外径与厚度
36 | 磁铁 | 两圈，每圈 18 个磁铁；设计目标为 10 × 2 mm，须核实实测尺寸和固定方式
1 | 完整 51105 推力轴承 | 25 × 42 × 11 mm
1 | 608 径向轴承 | 8 × 22 × 7 mm
4 | M4 盖板螺钉 | 按实际叠层检查长度和头型；没有已认可的标准采购长度
4 | M4 防转嵌入螺母 | 六角形；完全嵌入外壳螺母槽
4 | 下部木螺钉 | 木螺钉 4 × 30 mm，平头 Ø9；不要打印；未经验证的标称包络
4 | 上部木螺钉 | 木螺钉 4 × 40 mm；不要打印；V5 标称包络

51105 应作为完整轴承购买，包括两个座圈及滚动体。CAD 装配中将它们分开展示。对于 M4 螺钉，应测量实际穿过长度、螺母高度、头部和底部间隙；其包络并非某种螺钉长度的采购建议。

## 绕线与测量材料

准备起始线径为 0.18 mm 的漆包铜线、绝缘引线、合适的焊接与绝缘材料以及经过验证的应力释放措施。其他线径须先测量。固定材料和灌封材料必须与线漆、磁铁镀层和打印材料进行兼容性试验。

所需量具包括游标卡尺、千分尺、深度尺、塞尺、转速计、合适的真有效值万用表、温度探头和参数明确的功率电阻。测量小电阻时须计入测试线电阻，或使用四线测量。还需准备合适的 M4 与 M8 工具、护目镜及非磁性装配夹具。

# 4 打印准备

先在配备 0.4 mm 喷嘴的 Bambu P2S 上用 PLA 打印试样。使用与实际装载 PLA 对应的材料配置。切片软件中的 0.20 mm 层高只是仍需验证的起始设置。根据试样和完整逐层预览确定温度、冷却、墙线、填充和支撑。

CAD 中转子壁厚为 2 mm。确保切片软件能无间隙地生成薄壁区域。厚度本身不能证明强度；打印方向与层间结合也影响实际承载能力。

零件组 | 方向与检查
磁铁与轴承试样 | 凹槽朝上；配合面不得残留象脚或支撑材料。
底部模块 | 安装状态下磁铁槽朝下。在切片软件中比较 Z 轴朝上与翻转方向；检查磁铁槽、螺母槽和叶片过渡。
标准与顶部模块 | 检查导出的 Z 轴朝上方向；下卡爪与上锁扣轨道须保持畅通，打印后能够接近。
下磁转子 | 磁铁槽朝上；检查背部螺母槽和平台接触面。
外壳 | 封闭底部放在平台上，开口朝上；全面检查安装耳和螺钉通道。
线圈盒 | 支承面朝下，绕线空间朝上；键和电缆孔不得有毛刺。
盖板与上支架 | 若下表面能够获得干净支撑，优先使轴承座朝上；轴承座内不得残留支撑。

卡口顶部及倒扣需要经验证的桥接或可接近的支撑。不得在封闭锁扣轨道中留下无法取出的支撑。启动打印前检查预览的每一层；先打印试样，再做实际两级连接，最后打印整套。

ASA 是后续材料阶段。更换后须重新检查配合、翘曲、装配力、磁铁固定和载荷。仅更换材料并不能认可转子的耐候、耐热或连续运行能力。加工和通风须遵循实际耗材与打印机的说明。

# 5 检查配合试样与轴承

打印前测量实际轴承、磁铁和螺母。每个试样标注材料、配置和方向。尺寸合适的试样应能够在无裂纹、不歪斜且无失控外力的情况下装配；记录选择，并在打印大件前将其落实到设计中。

试样 | 发布的尺寸选项
51105 外径座孔 | 42 / 42.2 / 42.4 mm
51105 定心凸台 | 24.6 / 24.8 / 25 mm
608 外径座孔 | 22 / 22.2 / 22.4 mm
磁铁槽 | 10.8 / 11 / 11.2 mm
线圈盒径向间隙 | 0.3 / 0.35 / 0.4 mm

对于线圈盒弧段，先沿底板齐平切下凸弧，并去除切口毛刺，再与座孔弧段比较。该试样检查径向间隙，而非盖板最终形成的轴向约束。

分别测试卡口配对件和完整连接配对件。其专用紧配合的标称径向间隙为 0.20 mm、轴向间隙为 0.18 mm。插入后逆时针锁定并检查锁扣。加大的锁扣侧翼设计为卡合后几乎永久连接；反向旋转或拆卸可能损坏锁扣或模块。记录装配力、可见裂纹、轴向游隙和叶片接缝；不得强行反转释放锁扣。

## 51105 配合与方向

E11。三种座孔与三种定心直径供实际 51105 轴承选择。按 V5 发布文件打印两个独立试样。测试轴承 51105：25 × 42 × 11 mm。座孔 1：Ø 42.0 mm；座孔 2：Ø 42.2 mm；座孔 3：Ø 42.4 mm。凸台 1：Ø 24.6 mm；凸台 2：Ø 24.8 mm；凸台 3：Ø 25.0 mm。

E11 三种座孔和三种定心直径可用于配合实际 51105 轴承进行选择。

51105：25 × 42 × 11 mm。座圈静止安装在盖板中央座孔中。轴圈随底部模块旋转，并由其定心凸台定位。滚道朝向滚动体。依据实际几何形状及制造商标记区分座圈、轴圈与保持架，不得仅因外观相似而互换。

51105 承受转子的轴向载荷。装配时只对正在安装的圈施力，不得通过滚动体传力。不得通过拧紧打印件来把轴承当作压配工具。

## 608 配合与方向

E12。三种座孔直径检查实际 608 轴承与上支架的配合。608：8 × 22 × 7 mm。与 M8 螺纹的配合及运动自由度仍须实测。座孔 1：Ø 22.0 mm；座孔 2：Ø 22.2 mm；座孔 3：Ø 22.4 mm。

E12 三种座孔直径用于检查实际 608 轴承与上支架的配合。

608：8 × 22 × 7 mm。外圈安装在静止上支架中，内圈引导旋转的 M8 轴。滚动体在两圈之间运动。紫色 CAD 包络未细化这种内部运动。

M8 螺纹杆并不是磨削轴承轴颈。只有经过测量和受控加工后才能调整局部运转表面；之后须重新检查直径、跳动、剩余截面和内圈可靠支承。本设计未指定打印导向套。608 位置主要提供径向导向，须避免产生非预期的第二处轴向夹紧。

# 6 准备磁铁与试验线圈

测量包含镀层在内的磁铁直径和厚度。磁铁槽的直径与深度为 11 × 2 mm；这不能确认对目标尺寸为 10 × 2 mm 的磁铁形成可靠夹持。在试样上测试胶粘剂、镀层及保持能力。胶层厚度不得在未察觉时减小气隙。

1. 标记磁极面。 使用参考磁铁，将所有磁铁的同一极面做标记。安装前再次核对极性。佩戴护目镜，并用非磁性隔块将磁铁分开。

2. 安装上磁环。 朝向线圈的磁极沿圆周按 N S N S 交替。选择固定槽位作为起点并做标记，记录整个极性序列。

3. 对应下磁环。 在同一角位置，上方 N 极应正对下方 S 极，下一对则相反。关键是朝向线圈的磁极面。工作台上朝向相同的圆盘在翻面后，极性对应关系可能改变。

4. 检查保持能力。 将磁铁完全就位，并按实际固定产品要求等待固化。先分别检查两个磁环。每次旋转试验前，磁铁保持能力都是仍需单独确认的检查项目。

## 蛇形绕组试验

将绝缘导线连续绕过静止线圈盒中的 18 个圆角导向体，并交替从下一导向体的内侧和外侧通过。标记起点 A、终点 B 和完整路径。绕完全部 18 个导向体计为一匝；所有试验线圈必须采用相同路径和方向。

先用少量重复、手动旋转检查路径：相邻有效线段的感应贡献应相加。改变极性序列、反向线段或不同线路可能抵消电压。用照片或草图记录实际路径；线圈盒本身并未确定最终验证过的电气绕组。

导线 | 匝数 | 比较与测量
0.18 mm，须实测 | 20 | 在相同转速下比较电阻、绕组高度、开路电压及带载测量
0.18 mm，须实测 | 40 | 与 20 匝相同的路径和绕线方向
0.18 mm，须实测 | 80 | 只有实际绕组能装入已检查空间时才可安装

以后每测得一种导线直径，都要重复完整的 20、40、80 匝矩阵。须区分导体直径与含漆外径。目前没有最终匝数，也不保证输出功率。可用绕线空间不等于允许的最大发热量。

接线端必须位于有效运转间隙之外。焊点须绝缘，引线须进行机械应力释放，并检查导通及对其余装置的绝缘。永久灌封前先测量可拆卸试验线圈；灌封可能改变散热、维修性、高度和配合。

# 7 发电机装配

确保装置停转，并使用能控制磁环吸力的夹具。外壳开口朝上。检查螺母槽、肩台、键和电缆路径。封闭前将四个 M4 防转嵌入螺母完全装入。

1. 装入下磁转子。 从下方将 M8 扭矩螺母放入底部开口的螺母槽。 把下转子连同轴和一体式隔套装入外壳，磁极面朝上。磁铁载盘留在壳内，隔套自由穿过静止中心。螺母和轴端不得碰触封闭底部。

2. 装入线圈盒。 先检查绕组配合及绝缘。将线圈盒沿轴下降，落在外壳肩台上，并将单个键插入防转结构。侧面电缆孔必须对齐。

3. 安装静止盖板。 将电缆从侧面引出并做好应力释放。盖板平整就位，将四个 M4 螺钉交叉、分步拧紧；出现缝隙或变形时停止。外侧框架孔保持独立。PLA 尚无验证扭矩。

4. 安装 51105。 将静止座圈放在盖板定位座上，再装入滚动体和旋转轴圈，滚道相向。保持轴承清洁；用实际轴圈核对底部模块的定心凸台。

5. 安装底部模块。 装入上扭矩螺母，将底部模块沿轴下降至轴承上。磁极面朝下指向线圈。底部模块肩台支承在旋转轴圈上。用夹具限制磁吸力，手指不得进入间隙。

6. 测量运转间隙。 用手将轴完整转动一圈。检查每个角度是否接触、拉扯电缆或出现可见跳动。实际磁极面、绕组和胶层决定间隙。检查通过后才能继续安装转子叠组。

## 外壳内的下转子

E05. 下磁铁载盘在外壳内旋转；其一体式隔套穿过静止中心。 载盘具有 5 mm 平面打印面；凸起座含底部开口的 M8 螺母槽和上方一体套筒。 封闭壳底静止。下磁铁载盘旋转。磁铁向上朝线圈并旋转。M8 螺母位于向下开口的槽内，隐藏。上方一体套筒旋转。平坦打印面位于底部。

E05 下磁铁载盘在外壳内旋转；其一体式隔套穿过静止中心。

载盘的 5 mm 平面打印面贴在打印床上。凸起的中央座包含用于传递扭矩的底部开口的 M8 螺母槽。上方一体套筒随下转子旋转，静止线圈不得接触它。CAD 套筒外径与高度为 12 × 17.85 mm，M8 通孔为 8.8 mm。干装检查实际夹紧和底部间隙。物理刚度、桥接打印、尺寸配合、户外使用和动力驱动运行仍未经验证。

## 发电机安装顺序

E06。线圈盒、盖板和底部模块抬起，下磁转子留在剖开的外壳内。下转子位于静止绕组下方。图中显示完整的 V5.2 底部模块叶片。带上磁体托盘的底部模块 · 旋转 盖板和 51105 轴承座 · 静止 线圈盒 · 静止 有效绕组空间 · 静止 外壳内的下磁转子 · 旋转 外壳 / 底部安装耳 · 静止 4 × M4 盖板螺钉（显示 1 个）4 × 防转 M4 螺母（显示 1 个）两个磁环均有 18 个朝向绕组的磁极，上环 N 与 S 交替，下环 S 与 N 交替。在同一 +Z 投影中，相同角度处为相反磁极；0 度时上方为 N、下方为 S，20 度时上方为 S、下方为 N。

E06 线圈盒、盖板和底部模块抬起；下磁转子留在剖开的外壳内。

抬起的零件展示从上方进行装配的路径。绕组在两个旋转磁铁载盘之间保持静止。必须先装下磁转子，再装线圈盒和盖板；封闭后杯形外壳底部不提供装配入口。

## 推力轴承与载荷路径

E04。底部模块肩台支承在旋转轴圈上，座圈位于盖板内。51105：25 × 42 × 11 mm。滚动区域以包络表示；须验证实际轴承配合。底部肩台与 25-mm 凸台：旋转。51105 轴圈：旋转。51105 滚动区域：独立运动。51105 座圈：静止。带轴承座的盖板：静止。防转嵌入 M8 扭矩螺母。

E04 底部模块肩台支承在旋转轴圈上，静止座圈安装在盖板内。

转子载荷从底部模块肩台经轴圈、滚动体、座圈传至静止盖板，再经外壳传到下框架。M8 夹紧件连接旋转部件，不得夹住静止盖板或绕组。

## 检查上下气隙

E07。两个旋转磁铁载盘包围静止绕组，下转子位于外壳内。磁极面至有效绕组：上 1.5 mm，下 1.5 mm，包含塑料。机械间隙：磁铁至盖板 0.35 mm；磁铁至线圈盒底板 0.50 mm。底部模块及上磁铁载盘：旋转。绕组上方盖板：静止。绕线空间：静止。线圈盒及底板：静止。下磁转子：旋转。封底外壳：静止。下转子内的 M8 螺母。两圈各有 18 个朝向绕组的磁极，上方 N S 交替，下方 S N 交替。同一 +Z 投影中相同角度对应相反磁极；0 度时上 N 下 S，20 度时上 S 下 N。

E07 两个旋转磁铁载盘包围静止绕组；下转子位于外壳内。

从磁极面到有效绕组表面的标称距离，上方为 1.5 mm，下方为 1.5 mm。两处磁性间距都包括中间塑料：上方是盖板薄膜，下方是线圈盒底板。只有磁铁与槽口平齐或低于槽口时才适用。凸出量、胶层、绕组高度、轴向偏移和跳动都可能减小实际最小距离。

机械间隙更小：上方磁极面至盖板薄膜为 0.35 mm，下方磁极面至线圈盒底板为 0.50 mm。薄膜与线圈盒底板厚度均为 1.00 mm。线圈盒上缘与盖板下表面之间留有 0.15 mm，用于轴向保持。磁性间距和机械间隙须分别检查。

在完整手转一圈内测量，并检查现有轴向游隙。CAD 中无接触并不证明负载下仍有余量。发生摩擦时，不得通过磨合或提高转速来消除；应查明原因并修正装配。

## 固定线圈盒与盖板

E08。线圈盒落在外壳肩台上，盖板限制上移。−X 键防止转动。检查试样配合。盖板提供轴向保持。线圈盒带 18 个圆角导向体。外壳肩台与对应键槽。

E08 线圈盒落在外壳肩台上，盖板限制向上移动。

外壳肩台阻止线圈盒向下移动，配合环提供径向定心，键防止转动，螺钉固定的盖板限制向上移动。试装时必须具备这四项功能；松放的绕组载体不能投入运行。

## 检查盖板螺钉

E09。四个 M4 螺钉固定盖板；独立外孔将外壳固定到框架。凸台与框架孔共用径向轴线。从上方操作。4 个 M4 螺钉：静止。盖板有四孔。加强轴线。4 个嵌入 M4 螺母：静止。

E09 四个 M4 螺钉固定静止盖板；独立外侧孔将外壳固定到框架。

四个 M4 螺钉和四个防转六角螺母连接盖板与外壳。它们与四个独立框架孔位于同一径向轴线上，连续凸台加强下安装耳。螺钉从上方操作；盖板须平整且轴可自由旋转。

## 引出侧面电缆

E10。键正确插入时，线圈盒与外壳侧孔对齐。灰色包络为 Ø6 mm 自由电缆通道；不是已安装电缆，也不是密封。外壳开口在 45°；线圈盒开口在 45°。Ø6-mm 通道：参考体积。

E10 键正确就位后，线圈盒和外壳的侧面开孔对齐。

把绝缘引线穿过对齐的侧面开孔。电缆需要实际的应力释放和边缘保护；灰色包络仅表示电缆通道，并非已安装的电缆接头或密封。出口不防水。自由电缆须完全避开旋转件。

# 8 转子叠组装配

E01。一个底部模块、五个相同标准模块和一个顶部模块组成转子。插入位置分开展示，锁定后形成永久锁扣。第 1 级：底部模块，旋转。第 2 级：标准模块，旋转。第 3 级：标准模块，旋转。第 4 级：标准模块，旋转。第 5 级：标准模块，旋转。第 6 级：标准模块，旋转。第 7 级：顶部模块，旋转。M8 螺母与垫圈：旋转。

E01 一个底部模块、五个相同标准模块和一个顶部模块组成转子。

在已由轴承支承的底部模块上依次安装五个相同标准模块，最后安装顶部模块。M8 轴穿过开放中心和短导向区域。装配过程中始终防止叠组倾倒。

1. 对准插入位置。 对齐每个新模块的卡口凸爪和插入窗口。各模块具有平整齐平的叶片端部。中央卡口是唯一的形锁合扭矩接口。

2. 锁定该级。 从上方看，逆时针旋转至预定止挡。永久锁扣必须啮合。不要施加过大扭矩或用锤敲击；连接卡住时应检查试样与配合面。

3. 检查接缝。 锁定后检查叶片齐平接触、所有凸爪就位、锁扣和各接头的轴向间隙。发现明显错位或锁齿损坏时停止。完成检查后才能添加下一段。

4. 完成顶部夹紧。 将垫圈直接放在平整的顶部上板上，然后安装 M8 螺母。安装上轴承支架前先调好夹紧状态。拧紧不得使实际轴承运转或叶片连接受卡滞。

## 区分三种模块

E02. 七级结构由三种不同的一体式 CAD 模块构成。 平整齐平的叶片端部；中央卡口是唯一的形锁合扭矩接口。所有模块随 M8 轴旋转。 一体上磁铁载盘。51105 定位凸缘。下卡口销。上接收座和平整叶片端部。平整上部扭矩板。开放 M8 螺母座。

E02 七级结构由三种不同的一体式 CAD 模块构成。

底部模块带有上磁铁载盘及 51105 定心凸台。标准模块下方是凸接头，上方是凹接头。顶部模块以平整的上部扭矩板承托垫圈和 M8 夹紧，结束整个叠组。三种模块各为一个打印实体。

## 检查卡口与叶片接缝

E03. 平整齐平的叶片端部；中央卡口是唯一的形锁合扭矩接口。 对齐插入窗口，逆时针锁定，确认叶片齐平接触并检查锁扣。先用试样检查配合。 三个凸爪和永久锁齿。带斜坡和棘爪的接收座。标准模块：平整叶片端部和卡口。底座：平整叶片端部和接收座。

E03 平整齐平的叶片端部；中央卡口是唯一的形锁合扭矩接口。

锁扣用于永久连接。将转子叠组视为整体规划；更换线圈不应要求拆开六处级间连接。实际弹性插入与传力仍须通过试样及两级装配验证。

# 9 安装到木框架

首先完成顶部模块的 M8 夹紧调节并检查工具空间，再将加长 M8 轴穿过上轴承位置。框架间距和杆长应根据实际试装确定，需计入轴承、螺母、间隙及必要螺纹啮合长度。

1. 准备下框架。 支承面应平整并有足够承载能力。外壳通过四个底部安装耳落在木材上。四个下部木螺钉在旋转内部区域之外由上向下安装。按实际木材确定预钻孔、边距和螺钉长度。

2. 安装支架。 从上方将 608 放入静止支架的开放轴承座。用四个木螺钉由下向上把支架固定到上木框架下表面。下肩台防止轴承下落，木材封闭座孔并限制轴承向上移动。

3. 对准轴线。 最终固定四个螺钉前，使上支架与下轴承轴线对齐。轴必须无侧向约束地穿过 608。手转完整一圈，检查与顶部模块、垫圈和螺母之间的间隙。

4. 检查轴端。 加长轴须在内圈全宽范围内提供导向，并在有轴向游隙时仍可靠插入。在上木材处为轴端和运动预留空间。不得将突出轴端顶紧在木框架上。

E13。静止支架从下方固定到木框架，木材封闭轴承座。首先拧紧 M8 夹紧件。四个 4 × 40 mm 木螺钉为未经验证的标称包络。现有木框架：静止。608 轴承置于朝上开放的座孔。支架 80 × 50 × 12 mm：静止。4 个木螺钉由下向上安装。木材限制轴承向上移动。608 提供径向导向，座孔间隙 0.2 mm。下肩台限制轴承向下移动。贯穿的加长 M8 轴。

E13 静止支架从下方拧到木框架上，木材封闭轴承座。

## 上下木横梁之间的固定

E14。两木横梁之间：外壳从上方固定，上部 608 支架从下方拧紧。木材和木螺钉是参考件，不要打印。现场设计截面与固定方式，未认可承载能力。上木横梁：参考件，不要打印。608 支架：4 个木螺钉从下方安装。下木横梁：参考件，不要打印。底部安装耳：4 个木螺钉从上方安装。外壳底板和四个底部安装耳。4 × 30 mm，由上向下，标称包络。安装耳下表面落在木材上。木材与螺钉：不要打印。

E14 两木横梁之间：外壳从上方固定，上部 608 支架从下方拧紧。

图中下部使用 4 × 30 mm、上部使用 4 × 40 mm 的未经验证螺钉包络。木材截面仅为示例，不能据此认可现有围栏或任何特定风载。须在现场设计并检查固定方式和木材。

上轴承支架提供径向导向，轴向载荷计划由下部 51105 承担。拧紧后再次检查手转顺畅程度、轴承噪声、最小气隙与电缆间距，然后才能准备带防护的测量试验台。

# 10 测量与比较线圈

每个线圈都应在相同且已记录的转速和负载下比较。三个匝数组成试验矩阵。较高的开路电压本身不能说明哪种线圈在负载下更实用。

1. 静止时检查线圈。 记录线径、匝数、路径、绕组高度、电阻和环境温度。清晰标记导线端 A、B。检查与轴和磁铁载盘之间的绝缘。

2. 测量开路电压。 在防护装置内缓慢且受控地驱动。同时记录转速和交流开路电压。仪表带宽必须适合实际波形。测量接点断开不能被误判为发电机输出低。

3. 连接规定负载。 只使用事先确定额定能力合适的负载。在相同转速下记录电压、电流和温度。记录负载值、测量时间、环境和电缆状态。绕组过热、有异味、振动或接触时立即停止。

4. 比较结果。 纯电阻负载的平均功率可由恰当测得的有效值确定。存在整流器或脉冲电流时，应使用合适的直流或真实功率测量；不得未经核实就将交流读数相乘。

测量项目 | 每次试验应记录
标识 | 线圈编号、材料、实际导体直径、含漆直径、匝数及走线路径
机械数据 | 磁极序列、磁铁突出量、线圈高度、最小上下气隙
电气数据 | 冷态电阻、转速、交流开路电压、负载值、负载电压与负载电流
温度与时间 | 环境温度、线圈温度、测量时长及温度变化过程
观察 | 起动表现、噪声、振动、摩擦、松动零件及停止原因

根据开路电压按比例推算匝数，最多只是在磁场、路径不变且转速相同时的初步近似。电阻、铜填充率、空间和发热也会变化。每种推算出的绕组都必须重新制作实物线圈测试。

# 11 带防护试运行

首次旋转试验的前提是磁铁保持能力已确认、框架固定牢固、线圈盒约束闭合且能自由手转。设置防止零件飞出的防护屏障和安全停机手段。人员、头发、衣物及松散物体须远离旋转区域。

1. 静止检查。 检查螺钉位置标记、锁扣连接、轴承、电缆及两处气隙。清除异物。运动前固定电气测试线。

2. 缓慢开始。 在受控条件下逐步提高转速，每次改变后观察。目前没有已认可的最高转速。不得从本手册推导出可以进行自然风、暴风或超速试验。

3. 异常时停止。 摩擦、裂纹、磁铁位移、异常轴承声、发热或固定松动时，必须停机并查明原因。修正且重新手转检查后才能继续。

## 测量之后再选择充电电子设备

不得将发电机直接连接到 48-V 铅酸蓄电池，即使试验也不允许。标称电压和开路测量不足以选择充电系统。电池类型与充电曲线必须符合实际制造商要求。

今后的接线设计须包含整流、合适的充电控制、防反向电流、线缆与短路保护、安全隔离以及无负载时的能量耗散。按实测电压、电流、温升和故障条件选择元件。如需卸荷负载，须进行热和电气设计。本手册没有用于此目的的已认可电路图。

在此之前，开发仅限于规定的测量装置。自然风中自由运行、充电、进水、紫外线、霜冻、持续负载和无人值守运行均未验证。

# 12 维护与故障排查

## 取出线圈盒

1. 停机并支承。 机械锁定转子防止运动，在断电状态下断开电气导线。把转子叠组作为整体支承。拆卸时控制磁力和重量。

2. 清理上方通道。 固定叠组后松开上轴承支架，使轴脱离约束。用夹具固定下部旋转总成。卸载并抬起底部模块和上转子组，直到可接近 51105 及盖板。静止时松开必要的 M8 连接，不拆分级间锁扣。

3. 拆下盖板。 按方向分别放置轴承零件。松开四个盖板螺钉，抬起盖板并释放电缆。独立框架紧固件保持安装；下磁转子须固定在壳内。

4. 向上取出线圈盒。 小心跟送电缆，将键抬出槽，再沿已释放的轴向上取出线圈盒。不要拉扯导线。实际维护拆出路径须在试装时验证。

5. 重新装配。 按第 7 章顺序装配，重新对准上支架并测量全部间隙。更换线圈可能改变绕组高度和气隙。

每次试验前以及运输、更换材料或更换线圈后，检查裂纹、翘曲、游隙、螺钉标记、磁铁固定和绝缘。更换磨损或松动零件，并重复相关配合检查。

观察 | 静止时检查
转子摩擦 | 测量磁铁突出量、线圈高度、两处气隙、一体式转子隔套和轴向偏移。
轴承转动困难 | 检查轴承圈方向、座孔歪斜、上轴线对准和轴向夹紧。
线圈盒移动 | 检查肩台、键、配合环和平整就位的盖板是否存在打印缺陷。
电压低或无电压 | 检查转速、导线导通、焊点、极性序列和蛇形路径的电压叠加连接。
绕组发热 | 检查负载电流、绕组电阻、绝缘和散热；问题查清前不得继续旋转试验。
振动或螺母松动 | 检查跳动、磁铁分布、框架刚度和 M8 夹紧；不得通过提高转速绕过问题。

# 13 试验记录

每种装配方案单独记录日期、材料、打印配置及使用的发布文件。保留磁极序列、走线和实际装配照片。一次成功试验不代表获准连续或户外运行。

检查领域 | 所需证据
打印与配合 | 试样选项、实测尺寸、装配力、无裂纹状态及材料配置
机械装配 | 螺母啮合、轴承方向、轴长、框架固定及自由手转一圈
发电机 | 磁铁固定、极性序列、实际突出量及最小气隙
线圈 | 第 6 章矩阵及第 10 章测量数据，包括温度
后续试验 | 理由、未解决事项、停止条件及必要修正

## 查找图纸

ID | 文件
E01 | E01-rotorstapel.png
E02 | E02-modultypen.png
E03 | E03-bajonett-blattnaht.png
E04 | E04-base-51105-schnitt.png
E05 | E05-unterer-magnetrotor.png
E06 | E06-generator-explosion.png
E07 | E07-generator-schnitt.png
E08 | E08-kassettenrueckhaltung.png
E09 | E09-deckelverschraubung.png
E10 | E10-seitlicher-kabelausgang.png
E11 | E11-51105-passungsprobe.png
E12 | E12-608-passungsprobe.png
E13 | E13-oberer-halter.png
E14 | E14-zaunmontage.png
E15 | E15-gesamtbaugruppe.png

## 项目状态与结论限制

发布清单与尺寸：release/v5/manifest.json。图纸与图像说明：release/v5/drawings/figures.json。本手册适用于带静止发电机外壳和上轴承支架的 V5 装配。

实物配合、轴承保持、磁铁保持、电气功能、强度、疲劳寿命、超速和耐候表现仍需证明。CAD 间隙与封闭 STL 实体不能替代这些试验。只有确认测量结果后才能进入下一开发阶段。

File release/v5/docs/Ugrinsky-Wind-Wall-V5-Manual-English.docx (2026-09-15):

# Ugrinsky Wind Wall V5 Assembly Manual

Assembly and coil experiments for the PLA prototype

# 1 Purpose and limitations

This manual covers fit coupons, printing, assembly of the seven-stage rotor and comparable coil experiments. Begin with a guarded workshop setup. Actual measurements are required before selecting the winding, magnet retention and charging electronics.

Prototype status. V5 has not been physically validated. CAD checks confirm geometric properties, but do not establish a safe speed, fatigue life, output or suitability for unattended outdoor operation. The fits are not approved interference fits. The side cable outlet and housing are not waterproof.

Electrical limitation. Do not connect the generator directly to a 48-V lead-acid battery. Initial experiments must use only a guarded measurement setup with a defined, appropriately rated load.

Unvalidated concept visualization of a modern home and garden with one possible fence element containing ten slender vertical Ugrinsky rotors

Concept image A possible garden fence element with ten Ugrinsky rotors

Feature | V5 nominal value
Rotor stages | 7: 1 base, 5 standard, 1 top
Rotor diameter | 122 mm
Stage pitch and rotor height | 70 × 490 mm
Extended shaft envelope | 555.8 mm; not a final cutting dimension
Printed bodies | 12 from 8 different STL files

## Understanding the complete assembly

E15. Seven rotor stages and the generator are mounted between lower and upper timber rails. Timber / timber screws: do not print; design on site. CAD V5; fit, electrical function and operation are unvalidated. Upper timber rail · do not print. 608 support · 4 screws from below. Rotor · 1 base + 5 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

E15 Seven rotor stages and the generator are mounted between the lower and upper timber rails.

Ochre identifies the rotating assembly. Turquoise identifies stationary printed parts. Purple identifies bearing regions; their rolling elements and races move differently. Grey timber, screw and clearance references are not printed parts.

Both magnet carriers rotate together with the shaft, M8 clamping hardware and rotor stack. The coil, cassette, housing, cover and upper support remain stationary. The lower magnet rotor runs inside the housing below the stationary coil.

For reference: chapters 2 and 3 cover printed parts and purchased hardware; 4 and 5 printing and fit coupons; 6 to 9 winding and assembly; 10 and 11 measurement and commissioning; 12 and 13 maintenance, troubleshooting and experiment records.

# 2 Printed parts and files

Quantities cover one complete rotor, including the generator housing and upper support. The upper magnet carrier is integrated into the base. STL files are in release/v5/stl/ and matching STEP files in release/v5/step/.

Qty | Printed part | STL file | STEP file
1 | Base with upper magnet carrier | base_rotor_module.stl | base_rotor_module.step
5 | Standard module | standard_rotor_module.stl | standard_rotor_module.step
1 | Top module | top_rotor_module.stl | top_rotor_module.step
1 | Lower magnet rotor | lower_magnet_rotor.stl | lower_magnet_rotor.step
1 | Generator housing | generator_housing.stl | generator_housing.step
1 | Coil cassette | coil_cassette.stl | coil_cassette.step
1 | Stationary cover | generator_cover.stl | generator_cover.step
1 | Upper bearing support | top_support.stl | top_support.step

The base, standard, top and lower magnet rotor rotate. The housing, coil cassette, generator cover and upper bearing support are stationary. Release STLs sit on the print bed at Z = 0; this does not mean their printing orientation has been automatically optimised.

## Fit coupons and assemblies

Print each of the following coupons once for the initial fit check. Repeat whenever the material, profile or fit dimension changes. Coupon STLs are in release/v5/coupons/ and their STEP files in release/v5/step/.

Qty | Coupon STL file | Coupon STEP file
1 | magnet_pocket_coupon.stl | magnet_pocket_coupon.step
1 | 51105_outer_seat_coupon.stl | 51105_outer_seat_coupon.step
1 | 25mm_pilot_coupon.stl | 25mm_pilot_coupon.step
1 | 608_seat_coupon.stl | 608_seat_coupon.step
1 | coil_cassette_segment_coupon.stl | coil_cassette_segment_coupon.step
1 | bayonet_male.stl | bayonet_male.step
1 | bayonet_female.stl | bayonet_female.step
1 | joint_male.stl | joint_male.step
1 | joint_female.stl | joint_female.step

## Assemblies for inspection

release/v5/assembly/rotor_locked.step

release/v5/assembly/generator.step

release/v5/assembly/fence_assembly.step

These STEP assemblies support assembly inspection. The file fence_assembly.step includes the extended shaft for the upper support. Timber and purchased hardware are not exported from assemblies as printable parts.

# 3 Purchased parts and tools

The table describes the planned prototype. Purchase only after checking against the actual parts. Nominal envelopes do not establish thread engagement, screw-head seating or load capacity.

Qty | Component | Dimensions and selection
1 | M8 threaded rod | Extended shaft for the upper 608; cut only after dry assembly
3 | M8 nuts | Two positively engaged torque nuts and one upper clamping nut
1 | Upper M8 washer | 24 × 2 mm; outside dimension and thickness
36 | Magnets | Two rings of 18 magnets each; project target 10 × 2 mm, verify actual dimensions and retention
1 | Complete 51105 thrust bearing | 25 × 42 × 11 mm
1 | 608 radial bearing | 8 × 22 × 7 mm
4 | M4 cover screws | Check length and head shape against the actual stack; no approved catalogue length
4 | Captive M4 nuts | Hexagonal; fully seat in the housing pockets
4 | Lower timber screws | Timber screw 4 × 30 mm, flat head Ø9; do not print; unverified nominal envelope
4 | Upper timber screws | Timber screw 4 × 40 mm; do not print; V5 nominal envelope

Purchase the 51105 as a complete bearing, including both washers and rolling elements. These are shown separately in the CAD assembly. For the M4 screws, measure actual grip length, nut height, head and floor clearance; the envelope is not a purchasing recommendation for a particular screw length.

## Materials for winding and measurement

Prepare enamelled copper wire with an initial diameter of 0.18 mm, insulated leads, suitable soldering and insulating materials, and proven strain relief. Measure any other wire diameters first. Adhesives and potting compounds require compatibility tests with wire enamel, magnet coating and print material.

Required measuring equipment includes callipers, a micrometer, depth gauge, feeler gauges, tachometer, suitable True-RMS multimeter, temperature probe and defined power resistors. For low resistance, account for test-lead resistance or use four-wire measurement. Provide suitable M4 and M8 tools, safety glasses and a nonmagnetic assembly fixture.

# 4 Preparing to print

Start with PLA and the coupons on the Bambu P2S with a 0.4 mm nozzle. Use the material profile for the PLA actually loaded. Treat a 0.20 mm layer height as an initial slicer setting that still needs verification. Set temperature, cooling, wall lines, infill and supports only after inspecting the coupons and the complete layer preview.

The CAD rotor wall is 2 mm thick. Ensure the slicer produces thin wall regions without gaps. Thickness alone does not establish strength; orientation and layer adhesion also determine actual load capacity.

Part group | Orientation and checks
Magnet and bearing coupons | Pockets upwards; keep elephant foot and support residue away from mating surfaces.
Base | Magnet pockets face down when installed. Compare Z-up and inverted orientations in the slicer; inspect pockets, nut pocket and blade transitions.
Standard and top | Check the exported Z-up orientation; lower lugs and upper latch tracks must remain clear and accessible after printing.
Lower magnet rotor | Magnet pockets upwards; check the rear pocket and bed contact.
Housing | Closed floor on the bed, opening upwards; inspect every mounting tab and screw channel.
Cassette | Support face down, winding space up; key and cable opening free of burrs.
Cover and upper support | Prefer bearing seats upwards if the underside can be supported cleanly; leave no support residue in bearing seats.

Bayonet roofs and undercuts require verified bridging or accessible supports. Do not leave irremovable supports in enclosed latch tracks. Inspect every preview layer before starting; print coupons first, then a real two-stage joint, and only then the complete set.

ASA is a later material stage. After changing material, recheck fits, warping, joining forces, magnet retention and loading. A material change alone does not approve the rotor for weather, heat or continuous operation. Follow the processing and ventilation instructions for the actual filament and printer.

# 5 Checking fit coupons and bearings

Measure the actual bearings, magnets and nuts before printing. Mark material, profile and orientation on each coupon. A dimensionally suitable coupon must assemble without cracks, misalignment or uncontrolled force; record the choice and transfer it to the design before printing large parts.

Coupon | Release variants
51105 outer seat | 42 / 42.2 / 42.4 mm
51105 locating pilot | 24.6 / 24.8 / 25 mm
608 outer seat | 22 / 22.2 / 22.4 mm
Magnet pockets | 10.8 / 11 / 11.2 mm
Cassette radial clearance | 0.3 / 0.35 / 0.4 mm

For the cassette segment, first cut the male arc free flush with the plate and deburr the cut edge. Then compare it with the seat segments. The coupon checks radial clearance, not the final axial retention by the cover.

Test the bayonet pair and complete joint pair separately. Its dedicated tight fit has nominal radial clearance of 0.20 mm and nominal axial clearance of 0.18 mm. Insert, lock anticlockwise and inspect the latch. The enlarged latch flank is intended to remain practically permanent after engagement; reverse rotation or disassembly may damage the latch or module. Record force, visible cracks, axial play and blade seam; do not release the latch by forcefully turning backwards.

## 51105 fit and orientation

E11. Three housing seats and three pilot diameters allow selection using the actual 51105 bearing. Two separate printed coupons according to the V5 release. Test bearing 51105: 25 × 42 × 11 mm. Seat 1: Ø 42.0 mm. Seat 2: Ø 42.2 mm. Seat 3: Ø 42.4 mm. Pilot 1: Ø 24.6 mm. Pilot 2: Ø 24.8 mm. Pilot 3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

E11 Three housing seats and three pilot diameters allow selection using the actual 51105 bearing.

51105: 25 × 42 × 11 mm. The housing washer remains stationary in the central cover seat. The shaft washer rotates with the base and is aligned by its locating pilot. Raceways face the rolling elements. Identify washers and cage by their actual geometry and manufacturer markings; do not interchange them merely because they look similar.

The 51105 carries the axial rotor load. During fitting, press only on the washer being installed and do not transmit force through the rolling elements. Do not use the bearing as a fitting tool by clamping printed parts against each other.

## 608 fit and orientation

E12. Three seat diameters test the actual 608 bearing fit for the upper support. 608: 8 × 22 × 7 mm. Fit on the M8 thread and freedom of movement still require practical checks. Seat 1: Ø 22.0 mm. Seat 2: Ø 22.2 mm. Seat 3: Ø 22.4 mm.

E12 Three seat diameters test the fit of the actual 608 bearing for the upper support.

608: 8 × 22 × 7 mm. The outer ring sits in the stationary upper support; the inner ring guides the rotating M8 shaft. Rolling elements move between the rings. The purple CAD envelope does not resolve this internal motion.

An M8 threaded rod is not a ground bearing journal. Adapt a local running surface only after measurement and controlled machining; recheck diameter, runout, remaining cross-section and secure inner-ring seating. A printed guide sleeve is not specified. The 608 location provides mainly radial guidance; avoid unintended additional axial clamping.

# 6 Preparing magnets and the test coil

Measure magnet diameter and thickness including coating. The pockets are 11 × 2 mm in diameter and depth; they do not provide a confirmed clamping fit for a magnet with the project dimensions of 10 × 2 mm. Test adhesive, coating and retention on the coupon. Adhesive thickness must not reduce the gap unnoticed.

1. Mark the pole faces. Use a reference magnet and mark the same pole face on every magnet. Recheck polarity before insertion. Wear safety glasses and keep magnets separated with nonmagnetic spacers.

2. Populate the upper ring. The coil-facing poles alternate N S N S around the ring. Mark a fixed pocket as the starting position and record the entire pole sequence.

3. Match the lower ring. At the same angular position, an upper N pole faces a lower S pole; the next pair is reversed. The faces directed towards the coil are decisive. Discs facing the same way on the workbench can show a different correspondence after one is turned over.

4. Check retention. Seat magnets fully and allow the fastening system to cure according to the actual product. Check each ring separately first. Magnet retention remains an independent unresolved check before every rotation test.

## Experimental serpentine winding

Route the insulated wire as one continuous serpentine around the 18 rounded guide islands in the stationary cassette. Pass alternately along the inner and outer side of the next guide. Mark start A, end B and one complete path. For this experiment series, one complete circuit around all 18 guides counts as one turn. All test coils must use the same path and winding direction.

First check the path with a few repetitions while turning by hand: contributions from successive active sections should add. Changing the pole sequence, reversing sections or using other wire paths can cancel voltage. Document the actual path with a photograph or sketch; the cassette does not define a fully validated electrical winding.

Wire | Turns | Comparison and measurement
0.18 mm, measure actual wire | 20 | Resistance, winding height, open-circuit voltage and loaded measurement at equal speed
0.18 mm, measure actual wire | 40 | Same path and winding direction as for 20
0.18 mm, measure actual wire | 80 | Install only if the actual winding fits the verified space

Repeat the complete 20, 40 and 80 matrix for every wire diameter measured later. Distinguish conductor diameter from outside diameter including enamel. There is no final turn count and no guaranteed output. Do not confuse available winding space with maximum permissible heat generation.

Keep connection ends outside the active running gaps. Insulate solder joints, provide mechanical strain relief and check continuity and insulation from the rest of the assembly. Measure a removable test coil before permanent potting; potting can change heat removal, repairability, height and fit.

# 7 Assembling the generator

Work with rotation securely stopped and an assembly fixture that controls attraction between the magnet rings. The housing cup opens upwards. Check nut pockets, shoulder, key and cable route beforehand. Fully insert the four captive M4 nuts before closing.

1. Insert the lower magnet rotor. Insert the M8 torque nut into the bottom-open pocket from below. Insert the lower rotor with shaft and integral spacer sleeve into the cup, magnet faces upwards. The magnet carrier remains inside the housing while the sleeve runs freely through the stationary centre. The nut and shaft end must not touch the closed floor.

2. Insert the coil cassette. Check winding fit and insulation first. Lower the cassette over the shaft, seat it on the housing shoulder and engage the single key in its anti-rotation feature. The side cable openings must align.

3. Install the stationary cover. Route the cable through the side outlet and provide strain relief. Seat the cover flat and insert the four M4 screws into the captive nuts. Tighten evenly and incrementally in a crossing pattern; stop if a gap or deformation appears. The separate outer frame holes remain untouched. No tightening torque has been validated for PLA.

4. Install the 51105. Place the stationary housing washer on the cover seat, then install the rolling elements and rotating shaft washer with the raceways facing each other. Keep the bearing clean; check the base locating pilot against the actual shaft washer.

5. Fit the base. Insert the upper torque nut and lower the base onto the shaft and bearing. Its magnet faces point down towards the coil. The base shoulder bears on the rotating shaft washer. Limit magnetic attraction with the assembly fixture and keep fingers out of the gap.

6. Measure running clearances. Turn the shaft through a complete revolution by hand. Check every angle for contact, cable tension and visible runout. Actual magnet faces, winding and adhesive determine clearances. Continue with the rotor stack only after this check succeeds.

## Lower rotor inside the housing

E05. The lower magnet carrier runs inside the housing; its integral sleeve reaches through the stationary centre. Flat 5 mm print-side carrier; raised boss with bottom-open M8 nut pocket and upper integral sleeve. Closed housing floor · stationary. Lower carrier · rotating. Magnets facing up towar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

E05 The lower magnet carrier runs inside the housing; its integral sleeve reaches through the stationary centre.

The flat 5 mm carrier print surface rests on the bed. The raised central boss contains the bottom-open M8 nut pocket for torque transmission. The upper integral sleeve rotates with the lower rotor; the stationary coil must not touch it. The CAD sleeve is 12 × 17.85 mm outside diameter by height, with an 8.8 mm M8 passage. Dry-check actual clamping and floor clearance. Physical stiffness, bridge printability, dimensional fit, outdoor use and powered operation remain unvalidated.

## Generator installation order

E06. Cassette, cover and base are raised; the lower magnet rotor remains in the cut-away housing. Lower rotor below the stationary winding. The complete V5.2 base blades are shown. Base with upper magnet carrier · rotating Cover and 51105 seat · stationary Coil cassette · stationary Active winding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

E06 Cassette, cover and base are lifted; the lower magnet rotor remains in the cutaway housing.

The raised parts show access from above. The winding remains stationary between the two rotating magnet carriers. Install the lower magnet rotor before the cassette and cover; once closed, the cup floor provides no assembly access.

## Thrust bearing and load path

E04. The base shoulder bears on the rotating shaft washer; the housing washer sits in the cover. 51105: 25 × 42 × 11 mm. Rolling region shown as an envelope; verify actual bearing fit. Base shoulder and 25-mm pilot · rotating. 51105 shaft washer · rotating. 51105 rolling region · independent motio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

E04 The base shoulder bears on the rotating shaft washer; the housing washer sits in the cover.

Rotor load passes from the base shoulder through the shaft washer, rolling elements and housing washer into the stationary cover, then through the housing to the lower frame. The M8 clamp joins rotating parts; it must not clamp the stationary cover or winding.

## Checking both air gaps

E07. Two rotating magnet carriers surround the stationary winding; the lower rotor sits in the housing. Magnet face to active winding: 1.5 mm above / 1.5 mm below, including plastic. Mechanical: magnet to cover 0.35 mm; magnet to cassette floor 0.50 mm. Base / upper magnet carrier · rotating. Cove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

E07 Two rotating magnet carriers surround the stationary winding; the lower rotor sits in the housing.

Nominal distances from the magnet face to the active winding face are 1.5 mm above and 1.5 mm below. Both magnetic distances include the intervening plastic: the cover membrane above and the cassette floor below. They apply only when magnets sit flush with or below their pocket planes. Protrusion, adhesive, winding height, axial offset and runout can reduce the actual minimum distance.

Mechanical clearances are smaller: 0.35 mm above between magnet face and cover membrane, and 0.50 mm below between magnet face and cassette floor. Membrane and cassette floor are each 1.00 mm thick. There is 0.15 mm between cassette top and cover underside for axial retention. Check magnetic distances and mechanical clearances separately.

Measure over a complete hand revolution and check any axial play. A contact-free CAD state does not establish reserve clearance under load. If rubbing occurs, do not grind it in or clear it by increasing speed; locate the cause and correct the assembly.

## Securing cassette and cover

E08. The cassette rests on the housing shoulder; the cover limits upward travel. The single key at −X prevents rotation. Check fit on the segment coupon. Cover retains cassette axially. Cassette with 18 rounded guide islands. Housing shoulder and matching key groove.

E08 The cassette rests on the housing shoulder; the cover limits upward travel.

The housing shoulder supports the cassette downwards, the locating ring centres it radially and the key prevents rotation. The screwed cover limits upward travel. All four functions must be present during dry assembly; a loosely inserted winding carrier is not ready for operation.

## Checking cover screws

E09. Four M4 screws secure the stationary cover; separate outer holes fasten the housing to the frame. Boss and frame hole share the same radial axis. Access from above; check actual tools. 4 × M4 screw · stationary. Cover with four through holes. Reinforced boss-to-tab axes. 4 × captive M4 nut · 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

E09 Four M4 screws secure the stationary cover; separate outer holes fasten the housing to the frame.

Four M4 screws and four captive hex nuts connect cover and housing. They share radial axes with the four separate frame holes, and the continuous bosses reinforce the lower tabs. Screw access is from above. After tightening, the cover must sit flat and the shaft must still turn freely.

## Routing the side cable

E10. Side openings of cassette and housing align when the key is correctly inserted. Grey envelope = free cable passage Ø6 mm; no installed cable, no seal. Housing opening at 45°. Cassette opening at 45°. Ø6-mm passage · reference volume.

E10 The cassette and housing side openings align when the key is correctly seated.

Route the insulated leads through the aligned side openings. The cable requires actual strain relief and edge protection; the grey envelope only represents the cable passage. It is not an installed gland or seal. The outlet is not waterproof. Keep the free cable entirely outside rotating parts.

# 8 Assembling the rotor stack

E01. One base module, five identical standard modules and one top module form the rotor. Insertion positions exploded; permanent latch after locking. Stage 1: base module · rotating. Stage 2: standard module · rotating. Stage 3: standard module · rotating. Stage 4: standard module · rotating. Stag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

E01 One base module, five identical standard modules and one top module form the rotor.

Fit five identical standard modules above the base already supported by its bearing, followed by the top module. The M8 shaft passes through the open centres and short guide regions. Secure the stack against tipping throughout assembly.

1. Align the insertion position. Align the bayonet lugs and insertion windows for each new stage. The stages have plain flush blade ends. The central bayonet is the sole keyed torque interface.

2. Lock the stage. Viewed from above, lock counterclockwise to the intended stop. The permanent latch must engage. Do not apply excessive torque or use a hammer; if the joint jams, inspect the coupons and mating surfaces.

3. Check the seam. After locking, verify flush blade contact, every lug seat, the latch and axial play at each joint. Stop for visible misalignment or a damaged latch tooth. Add the next section only after this check.

4. Close the upper clamp. Place the washer directly on the flat upper top plate and fit the M8 nut. Adjust the clamp before installing the upper bearing support. Tightening must not bind the actual bearing motion or blade joints.

## Distinguishing the three module types

E02. The seven stages use three different single-body CAD module types. Plain flush blade ends; the central bayonet is the sole keyed torque interface. All modules rotate with the M8 shaft. Integral upper magnet carrier. Locating collar for 51105. Lower bayonet spigot. Upper receiver and plain bla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

E02 The seven stages use three different single-body CAD module types.

The base includes the upper magnet carrier and 51105 locating pilot. The standard module has the male joint below and the female joint above. The top module completes the stack with a flat upper torque plate for the washer and M8 clamp. Each of the three types is a single printed body.

## Checking bayonet and blade seam

E03. Plain flush blade ends; the central bayonet is the sole keyed torque interface. Align insertion windows; lock counterclockwise; verify flush blade contact and inspect latch. Test fit on coupons. Three lugs + permanent latch teeth. Receiver with ramps and locking pawls. Standard: plain blade e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

E03 Plain flush blade ends; the central bayonet is the sole keyed torque interface.

The latch is intended as a permanent joint. Plan the rotor stack as one unit; changing the coil should not require separating its six stage joints. Actual elastic insertion and force transmission still require confirmation with coupons and a two-stage assembly.

# 9 Mounting on the timber frame

Finish adjusting the M8 clamp at the top module and check tool access first. Then guide the extended M8 shaft through the upper bearing location. Frame spacing and rod length must be established by actual dry assembly, including bearings, nuts, clearances and necessary thread engagement.

1. Prepare the lower frame. Provide a flat, load-bearing support. The housing rests on the timber through four floor tabs. Insert the four lower timber screws from top to bottom, outside the rotating interior. Determine pilot drilling, edge distance and screw length for the actual timber.

2. Install the support. Insert the 608 from above into the stationary support's open bearing seat. Attach the support against the upper timber frame using four timber screws from bottom to top. The lower shoulder retains the bearing downwards; the timber closes the seat and retains it upwards.

3. Align the shaft. Align the upper support with the lower bearing axis before finally securing the four screws. The shaft must run through the 608 without lateral constraint. Check clearance to the top module, washer and nut over a complete hand revolution.

4. Check the shaft end. The extended shaft must guide the full width of the inner ring and remain securely engaged even with axial play. Provide space at the upper timber for the shaft end and movement. Do not force the projecting end against the timber frame.

E13. The stationary support screws to the timber frame from below; timber closes the bearing seat. Tighten the M8 clamp first. Four 4 × 40 mm timber screws are unverified nominal envelopes. Existing timber frame · stationary. 608 bearing in upward-open seat. Support 80 × 50 × 12 mm · stationary. 4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

E13 The stationary support screws to the timber frame from below; the timber closes the bearing seat.

## Mounting between the timber rails

E14. Between two timber rails: housing secured from above, upper 608 support screwed from below. Timber and timber screws: references, do not print. Design sections and fixings on site; no load approval. Upper timber rail · reference, do not print. 608 support · 4 timber screws from below. Lower t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

E14 Between two timber rails: housing fastened from above and upper 608 support screwed from below.

The drawing uses unverified screw envelopes of 4 × 30 mm below and 4 × 40 mm above. Timber sections are examples. They do not approve the existing fence or a particular wind load. Design and verify the fixings and timber on site.

The upper bearing support provides radial guidance. The lower 51105 is intended to carry axial load. After fastening, recheck free hand rotation, bearing noise, minimum air gaps and cable clearance. Only then prepare the guarded test stand for measurements.

# 10 Measuring and comparing coils

Compare each coil at the same recorded speeds and with the same load. The three turn counts form an experimental matrix. A higher open-circuit value alone does not identify the coil that performs usefully under load.

1. Check the coil with the rotor stopped. Record wire diameter, turn count, path, winding height, resistance and ambient temperature. Clearly mark conductor ends A and B. Check insulation from shaft and magnet carriers.

2. Measure open-circuit voltage. Drive slowly and controllably in the guarded setup. Record speed and AC open-circuit voltage simultaneously. Instrument bandwidth must suit the actual waveform. Do not interpret a disconnected measuring contact as low generator output.

3. Connect a defined load. Use only a load that has already been appropriately rated. At the same speed, record voltage, current and temperature. Record load value, measurement duration, surroundings and cable condition. Stop immediately if the winding becomes hot, or if odour, vibration or contact occurs.

4. Compare results. For purely resistive loads, average power can be determined from appropriately measured RMS values. With a rectifier or pulsed current, use suitable DC or true power measurement; do not multiply AC readings without verification.

Measurement | Record for every experiment
Identification | Coil identifier, material, actual conductor diameter, enamelled diameter, turns and wire path
Mechanical data | Magnet pole sequence, magnet protrusion, coil height, minimum upper and lower air gaps
Electrical data | Cold resistance, speed, AC open-circuit voltage, load value, load voltage and load current
Heat and time | Ambient temperature, coil temperature, measurement duration and temperature history
Observation | Starting behaviour, noise, vibration, rubbing, loose parts and reason for stopping

Scaling turn count from open-circuit voltage is at most an initial approximation with unchanged magnetic field and path at the same speed. Resistance, copper fill, space and heating also change. Every derived winding must be tested again as an actual coil.

# 11 Guarded commissioning

The first rotation test requires confirmed magnet retention, secure frame attachment, closed cassette retention and free hand rotation. Provide shielding against ejected parts and a safe means of stopping. Keep people, hair, clothing and loose objects away from rotation.

1. Check at standstill. Inspect screw witness marks, latches, bearings, cable and both air gaps. Remove foreign objects. Secure electrical test leads before movement.

2. Start slowly. Increase rotation in steps under controlled conditions and observe after every change. No maximum speed has been approved. Do not infer permission for wind, storm or overspeed tests from this manual.

3. Stop on abnormalities. Rubbing, cracks, magnet movement, unusual bearing noise, heating or loose fixings require stopping and investigating the cause. Continue only after correction and another hand-rotation check.

## Select charging electronics only after measurements

Do not connect the generator directly to a 48-V lead-acid battery, even experimentally. Nominal voltage and open-circuit readings are insufficient for selecting a charging system. Battery type and charging profile must match the actual manufacturer's requirements.

A future connection design must cover rectification, suitable charge control, reverse-current blocking, cable and short-circuit protection, safe isolation and energy dissipation when the load is absent. Select components using measured voltage, current, heat and fault conditions. Any necessary dump load requires thermal and electrical design. This manual contains no approved circuit diagram for that purpose.

Until then, development remains on the defined measurement setup. Free running in wind, charging, water ingress, UV exposure, frost, continuous load and unattended operation have not been validated.

# 12 Maintenance and troubleshooting

## Removing the coil cassette

1. Stop and support. Mechanically secure the rotor against movement and disconnect electrical leads with power isolated. Support the rotor stack as one unit. Control magnetic forces and weight during removal.

2. Clear access from above. With the stack secured, release the upper bearing support and free the shaft. Hold the lower rotating assembly with a fixture. Unload and lift the base and upper rotor assembly enough to access the 51105 and cover. Release necessary M8 connections at standstill without separating the stage latches.

3. Remove the cover. Set bearing parts aside separately according to orientation. Undo the four cover screws, lift off the cover and release cable strain relief. The separate frame fasteners remain installed; keep the lower magnet rotor secured in the housing.

4. Lift out the cassette upwards. Carefully feed the cable, lift the key out of its groove and remove the cassette upwards over the freed shaft. Do not pull the wire. Verify the actual service path during dry assembly.

5. Reassemble. Assemble in the sequence in chapter 7, realign the upper support and measure all clearances again. Changing the coil can change winding height and air gaps.

Before every experiment session and after transport, material changes or coil changes, inspect cracks, warping, play, screw marks, magnet attachment and insulation. Replace worn or loose parts and repeat the affected fit check.

Observation | Check at standstill
Rotor rubs | Measure magnet protrusion, coil height, both air gaps, the integral rotor sleeve and axial offset.
Bearing is stiff | Check washer orientation, cocked seats, upper shaft alignment and axial binding.
Cassette moves | Inspect shoulder, key, locating ring and flat-seated cover for printing defects.
Low or no voltage | Check speed, wire continuity, solder joints, pole sequence and additive connection of the serpentine path.
Winding gets hot | Check load current, winding resistance, insulation and heat removal; do not run another rotation test until resolved.
Vibration or loose nuts | Check runout, magnet distribution, frame stiffness and M8 clamping; do not try to pass through it by increasing speed.

# 13 Recording experiments

Keep a separate record for each build variant, including date, material, print profile and release files used. Retain photographs of pole sequence, wire routing and actual assembly. One successful experiment does not approve continuous or outdoor operation.

Check area | Required evidence
Printing and fits | Coupon variant, actual dimensions, joining forces, absence of cracks and material profile
Mechanical assembly | Nut engagement, bearing orientation, shaft length, frame mounting and free hand revolution
Generator | Magnet retention, pole sequence, actual protrusion and minimum air gaps
Coil | Matrix from chapter 6 and measurements from chapter 10 including temperature
Further experiment | Rationale, unresolved points, stopping criteria and necessary corrections

## Finding the drawings

ID | File
E01 | E01-rotorstapel.png
E02 | E02-modultypen.png
E03 | E03-bajonett-blattnaht.png
E04 | E04-base-51105-schnitt.png
E05 | E05-unterer-magnetrotor.png
E06 | E06-generator-explosion.png
E07 | E07-generator-schnitt.png
E08 | E08-kassettenrueckhaltung.png
E09 | E09-deckelverschraubung.png
E10 | E10-seitlicher-kabelausgang.png
E11 | E11-51105-passungsprobe.png
E12 | E12-608-passungsprobe.png
E13 | E13-oberer-halter.png
E14 | E14-zaunmontage.png
E15 | E15-gesamtbaugruppe.png

## Project status and limits of claims

Release inventory and dimensions: release/v5/manifest.json. Drawings and image descriptions: release/v5/drawings/figures.json. This manual applies to the V5 assembly with stationary generator housing and upper bearing support.

Physical fit, bearing retention, magnet retention, electrical function, strength, fatigue life, overspeed and weather behaviour still require evidence. CAD clearances and closed STL bodies do not replace these experiments. Confirmed measurements are required before the next development step.

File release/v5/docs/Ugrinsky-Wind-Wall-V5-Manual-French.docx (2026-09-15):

# Ugrinsky Wind Wall V5 Manuel de montage

Montage et essais de bobines du prototype en PLA

# 1 Objectif et limites

Ce manuel décrit les éprouvettes d'ajustement, l'impression, le montage du rotor à sept étages et des essais comparables de bobines. Commencez par un montage protégé en atelier. Seules des mesures réelles permettent de choisir le bobinage, la fixation des aimants et l'électronique de charge.

État du prototype. V5 n'est pas validé physiquement. Les contrôles CAO confirment des propriétés géométriques, mais aucune vitesse sûre, tenue en fatigue, puissance ou aptitude au fonctionnement extérieur sans surveillance. Les ajustements ne sont pas des emmanchements serrés approuvés. La sortie latérale du câble et le boîtier ne sont pas étanches à l'eau.

Limite électrique. Ne raccordez pas directement le générateur à une batterie au plomb de 48-V. Pour les premiers essais, utilisez exclusivement un montage de mesure protégé avec une charge définie et correctement dimensionnée.

Concept non validé d’une maison moderne et d’un jardin avec un élément de clôture possible comportant dix rotors Ugrinsky verticaux et élancés

Image conceptuelle Un élément de clôture de jardin possible avec dix rotors Ugrinsky

Caractéristique | Valeur nominale V5
Étages du rotor | 7 : 1 base, 5 standard, 1 sommet
Diamètre du rotor | 122 mm
Pas des étages et hauteur du rotor | 70 × 490 mm
Enveloppe de l'arbre prolongé | 555,8 mm ; pas une cote définitive de coupe
Corps imprimés | 12 provenant de 8 fichiers STL différents

## Comprendre l'ensemble complet

E15. Sept étages et générateur entre traverses inférieure et supérieure. Bois / vis à bois : ne pas imprimer, dimensionner sur place. CAO V5 ; ajustement, électricité et fonctionnement non validés. Traverse supérieure · ne pas imprimer. Support 608 · 4 vis du dessous. Rotor · 1 base + 5 standard +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

E15 Sept étages de rotor et le générateur sont montés entre les traverses en bois inférieure et supérieure.

L'ocre désigne l'ensemble tournant. Le turquoise désigne les pièces imprimées fixes. Le violet indique les zones de roulement ; leurs éléments roulants et bagues ont des mouvements différents. Les références grises de bois, vis et dégagements ne sont pas des pièces à imprimer.

Les deux porte-aimants tournent avec l'arbre, le serrage M8 et l'empilage du rotor. La bobine, la cassette, le boîtier, le couvercle et le support supérieur restent fixes. Le rotor magnétique inférieur tourne à l'intérieur du boîtier, sous la bobine fixe.

Pour retrouver une information : chapitres 2 et 3, pièces et quincaillerie ; 4 et 5, impression et éprouvettes ; 6 à 9, bobinage et montage ; 10 et 11, mesures et mise en service ; 12 et 13, maintenance, diagnostic et journal d'essais.

# 2 Pièces imprimées et fichiers

Les quantités concernent un rotor complet, avec boîtier du générateur et support supérieur. Le porte-aimants supérieur est intégré à la base. Les STL sont dans release/v5/stl/ et les STEP correspondants dans release/v5/step/.

Qté | Pièce imprimée | Fichier STL | Fichier STEP
1 | Base avec porte-aimants supérieur | base_rotor_module.stl | base_rotor_module.step
5 | Module standard | standard_rotor_module.stl | standard_rotor_module.step
1 | Module de sommet | top_rotor_module.stl | top_rotor_module.step
1 | Rotor magnétique inférieur | lower_magnet_rotor.stl | lower_magnet_rotor.step
1 | Boîtier du générateur | generator_housing.stl | generator_housing.step
1 | Cassette de bobine | coil_cassette.stl | coil_cassette.step
1 | Couvercle fixe | generator_cover.stl | generator_cover.step
1 | Support du roulement supérieur | top_support.stl | top_support.step

La base, les modules standard et de sommet et le rotor magnétique inférieur tournent. Boîtier, cassette, couvercle et support supérieur sont fixes. Les STL publiés reposent sur le plateau à Z = 0 ; leur orientation d'impression n'est pas pour autant optimisée automatiquement.

## Éprouvettes et assemblages

Imprimez une fois chacune des éprouvettes suivantes pour le premier contrôle. Répétez-les après changement de matériau, profil ou cote d'ajustement. Les STL sont dans release/v5/coupons/ et leurs STEP dans release/v5/step/.

Qté | STL de l'éprouvette | STEP de l'éprouvette
1 | magnet_pocket_coupon.stl | magnet_pocket_coupon.step
1 | 51105_outer_seat_coupon.stl | 51105_outer_seat_coupon.step
1 | 25mm_pilot_coupon.stl | 25mm_pilot_coupon.step
1 | 608_seat_coupon.stl | 608_seat_coupon.step
1 | coil_cassette_segment_coupon.stl | coil_cassette_segment_coupon.step
1 | bayonet_male.stl | bayonet_male.step
1 | bayonet_female.stl | bayonet_female.step
1 | joint_male.stl | joint_male.step
1 | joint_female.stl | joint_female.step

## Assemblages de contrôle

release/v5/assembly/rotor_locked.step

release/v5/assembly/generator.step

release/v5/assembly/fence_assembly.step

Ces assemblages STEP servent au contrôle du montage. fence_assembly.step contient l'arbre prolongé destiné au support supérieur. Le bois et les composants achetés ne sont pas exportés des assemblages comme pièces imprimables.

# 3 Pièces achetées et outils

Le tableau décrit le prototype prévu. N'achetez qu'après comparaison avec les pièces réelles. Les enveloppes nominales ne prouvent ni engagement des filets, ni assise des têtes de vis, ni capacité de charge.

Qté | Composant | Dimensions et choix
1 | Tige filetée M8 | Arbre prolongé pour le 608 supérieur ; couper seulement après montage à blanc
3 | Écrous M8 | Deux écrous transmettant le couple par engagement de forme et un écrou supérieur de serrage
1 | Rondelle M8 supérieure | 24 × 2 mm ; dimension extérieure et épaisseur
36 | Aimants | Deux couronnes de 18 aimants ; objectif 10 × 2 mm, vérifier dimensions réelles et retenue
1 | Butée à billes 51105 complète | 25 × 42 × 11 mm
1 | Roulement radial 608 | 8 × 22 × 7 mm
4 | Vis M4 du couvercle | Vérifier longueur et tête sur l'empilage réel ; aucune longueur commerciale approuvée
4 | Écrous captifs M4 | Hexagonaux ; les engager complètement dans les logements du boîtier
4 | Vis à bois inférieures | Vis à bois 4 × 30 mm, tête plate Ø9 ; ne pas imprimer ; enveloppe nominale non vérifiée
4 | Vis à bois supérieures | Vis à bois 4 × 40 mm ; ne pas imprimer ; enveloppe nominale V5

Achetez la 51105 complète avec ses deux rondelles et ses éléments roulants, représentés séparément dans l'assemblage CAO. Pour les vis M4, mesurez longueur traversée réelle, hauteur d'écrou, tête et dégagement du fond ; l'enveloppe ne recommande pas l'achat d'une longueur particulière.

## Matériel de bobinage et de mesure

Préparez du cuivre émaillé de diamètre initial 0,18 mm, des fils de raccordement isolés, des produits de soudure et d'isolation adaptés, ainsi qu'une décharge de traction éprouvée. Mesurez d'abord tout autre diamètre de fil. Colles et résines d'enrobage nécessitent un essai de compatibilité avec l'émail, le revêtement des aimants et le matériau imprimé.

Prévoyez pied à coulisse, micromètre, jauge de profondeur, cales d'épaisseur, tachymètre, multimètre True-RMS adapté, sonde thermique et résistances de puissance définies. Pour les faibles résistances, tenez compte des cordons ou utilisez une mesure à quatre fils. Ajoutez outils M4 et M8 appropriés, lunettes de protection et dispositif de montage non magnétique.

# 4 Préparer l'impression

Commencez avec le PLA et les éprouvettes sur la Bambu P2S à buse de 0,4 mm. Utilisez le profil du PLA réellement chargé. Une hauteur de couche de 0,20 mm est un point de départ à vérifier. Définissez température, refroidissement, parois, remplissage et supports d'après les éprouvettes et l'aperçu complet des couches.

La paroi du rotor mesure 2 mm en CAO. Vérifiez que le trancheur produit les zones minces sans lacunes. L'épaisseur seule ne confirme pas la résistance ; orientation et adhésion des couches influencent aussi la tenue réelle.

Groupe de pièces | Orientation et contrôle
Éprouvettes d'aimant et de roulement | Logements vers le haut ; éviter pied d'éléphant et résidus de supports sur les portées.
Base | En montage, les logements d'aimants ouvrent vers le bas. Comparez Z vers le haut et la position retournée dans le trancheur ; vérifiez logements, écrou et transitions de pales.
Standard et sommet | Vérifier l'orientation exportée Z vers le haut ; les griffes inférieures et pistes supérieures doivent rester libres et accessibles après impression.
Rotor magnétique inférieur | Logements d'aimants vers le haut ; vérifier logement arrière et contact avec le plateau.
Boîtier | Fond fermé sur le plateau, ouverture en haut ; examiner entièrement pattes et passages de vis.
Cassette | Appui en bas, espace de bobinage en haut ; clavette et ouverture de câble sans bavure.
Couvercle et support supérieur | Préférer les sièges de roulement vers le haut si le dessous peut être soutenu proprement ; aucun résidu dans les sièges.

Les toits de baïonnette et contre-dépouilles nécessitent des ponts vérifiés ou des supports accessibles. Ne laissez aucun support impossible à retirer dans les pistes fermées. Examinez chaque couche avant lancement ; d'abord les éprouvettes, puis une liaison réelle de deux étages, enfin le jeu complet.

L'ASA est une étape matérielle ultérieure. Après changement, vérifiez à nouveau ajustements, gauchissement, efforts d'assemblage, fixation des aimants et charge. Changer de matériau n'autorise pas à lui seul intempéries, chaleur ou service continu. Respectez les consignes de mise en œuvre et de ventilation du filament et de l'imprimante employés.
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

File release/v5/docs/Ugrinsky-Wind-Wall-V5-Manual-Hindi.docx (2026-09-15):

# Ugrinsky Wind Wall V5 संयोजन पुस्तिका

PLA प्रोटोटाइप का संयोजन और कॉइल प्रयोग

# 1 उद्देश्य और सीमाएँ

यह पुस्तिका फिट परीक्षण नमूनों, प्रिंटिंग, सात चरणों वाले रोटर के संयोजन और तुलनीय कॉइल प्रयोगों का मार्गदर्शन देती है। पहले कार्यशाला में सुरक्षा आवरण वाला परीक्षण संयोजन बनाएँ। वास्तविक माप के बाद ही वाइंडिंग, चुंबक की पकड़ और चार्जिंग इलेक्ट्रॉनिक्स चुने जा सकते हैं।
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

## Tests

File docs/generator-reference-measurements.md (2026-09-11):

# Generator reference measurements

These are STL measurements, not physical magnet or bearing measurements.
The original downloaded files remain external to the repository. Binary STL
triangles were sliced with `slice_triangles`/`join_segments` from the existing
measurement script; circular contours were fitted with a 0.05 mm maximum RMS.
No reference mesh enters production CadQuery geometry.

| External file | Measured features, mm | Reconstruction decision |
| --- | --- | --- |
| `3 magnet_ring (2).stl` | Envelope 103.994 x 103.994 x 10; disc z=0..3, floor z=0.998; 18 pockets approximately 11.004 diameter on radius 44.5; shaft hole 8.205; rear boss about 20 diameter | Regularize pockets to 11 x 2. Increase OD to 106 and floor to 3 for loaded walls. Use common 8.8 shaft bore, 34 hub and ribs; total height 10. |
| `2 Coil_Former.stl` | Envelope 118 x 118 x 12; floor 2; cavity diameter 114.005; center bore 12.405; upper center opening 42.505, center boss OD60; 18 rounded guide contours at mid-height | Reconstruct the functional 18-island open serpentine guide in the removable cassette while retaining the V5 housing interface. |
| `4 Stator_Cover_PLate.stl` | 112 OD, 62.005 ID, thickness 2 | Separate 112/62 x 2 annulus above former, conservative 14 total. |
| `1 Base.stl` | 120 OD, cavity 114.006, height 27, floor 3 | Keep cup envelope, add parameterized through-bore/boss for shaft bearing reference. |
| `5 Top_Bearing.stl` | Central bore 12.305, upper boss OD20, overall height14; outer fitting is noncircular | Does not identify an 8 mm bearing product. Reserve provisional 12 OD, 8 ID, 6 long sleeve in 12.3 seat; axial retention remains open. |

Pocket fits at source z=1 mm yield radii 5.5018..5.5027 mm with RMS below
0.00034 mm; these are mesh-fit residuals, not manufacturing accuracy. Slices
at z=0.5 have only the outer contour and shaft hole, while z=1.5 and 2.5 also
have all 18 pockets. Unique ring Z planes are 0, 0.998, 3 and 10 mm, establishing
the blind pocket depth. Polygon interpolation reduces the fitted outer radius
slightly; the envelope dimensions are used for nominal OD. The source rear
boss center is offset approximately (0.097,-0.203) mm from its shaft axis;
the reconstruction explicitly centers every rotating/stationary interface.

The CAD coupon provides 10.8, 11.0 and 11.2 mm diameters with the same 2 mm
depth and a 3 mm floor. Actual magnet diameter, thickness, protrusion and
retention need physical verification. The nominal 1.5 mm gaps are measured
from carrier pocket planes and only bound magnets that are flush or recessed.

Source SHA-256 fingerprints:

| File | SHA-256 |
| --- | --- |
| Magnet ring | `f838e07b7d8b0bba026da2a16ac24db00db2e2a82593bac2e12a3e302d5315f2` |
| Coil former | `118014450fdb95d35e3b54a70433b43965bff0429117a6b3ead8034dfc92dd15` |
| Cover | `4595dd91982b0b855eb9213f087ba8558134e393ad1d67a340f122bf599af6e1` |
| Base | `31c3883c701b0496af80390d83a7dd05ace5eba325551d031f61dc94d46ef3c2` |
| Top bearing feature | `7820a23cad35b0c7bda16438d50e9a4688b4403797a426ecf0330a12e895906b` |

Detailed local evidence: `build/generator-reference-measurements.json`,
`build/generator-reference-sections.png`, and `build/measure_generator.py`.
These derived reports and scripts are local ignored artifacts, not source meshes.

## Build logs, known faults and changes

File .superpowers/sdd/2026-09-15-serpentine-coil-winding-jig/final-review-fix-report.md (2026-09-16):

# Final review fix wave 1/1 — serviceable winding tools

## Scope

Worktree: `C:/Users/fi87roy/Documents/GitHub/windwall/.worktrees/serpentine-coil-winding-jig`.
Branch: `codex/serpentine-coil-winding-jig`. Fix-wave baseline: `a7855a3`.
Whole-branch baseline: `0fbebe9`.

Read the complete final-review brief, progress ledger, implementation plan,
design specification, Task 1–8 reports, relevant source/tests, operator guide,
assembly contract, scripts and generated release. The supplied engineering
instructions apply. Used strict test-first regressions, systematic diagnosis
of the resulting geometric failures, and fresh verification before handoff.
No subagent, merge, push, unrelated refactor or new dependency was used.

## Findings and mechanical decisions

1. **Axial spindle restraint:** two custom steel shoulder collars are positively
   cross-pinned to the shaft on opposite sides of the left 608 inner ring.
   Each Ø10.4 mm nose leaves a nominal 0.1 mm face gap. The right 608 does not
   axially locate the shaft, avoiding preload across the support span. Two
   identical printed outer-ring caps bolt to the uprights. Upright shoulders
   and caps contact only radii 10–11 mm; collars contact radii 4.1–5.2 mm.
   A displaced shaft/collar engages its cross-pin; each collar engages the
   left inner ring in the relevant axial direction; outer-ring displacement
   engages either its shoulder or cap. Purchased bearing lands and actual
   endplay must be measured. Pin/hole and bearing internal clearance add to
   the two face gaps: 0.2 mm is not a total endplay claim.
2. **Complete removal:** retract all six ribs and their retained hardware by
   2 mm through a common cam position. A real annular taped-coil surrogate
   travels with the supported head. Remove four vertical head/locator pins
   and the side crank pin, pull the shaft 220 mm left, lift head/coil 200 mm,
   then slide the coil 50 mm axially off the ribs above the frame. Uprights
   and bearing caps remain installed. A helper holds the loose head stack,
   crank and collars; keepers are removed before the modeled pins. The route
   checks 21 positions in every stage at Ø110, Ø127 and Ø145.
   The surrogate bounds 10 mm axial winding width, 3 mm radial build and
   0.5 mm inward tape allowance; it does not certify arbitrary winding sizes.
   The full route additionally exposed an old pin/nut interference and a
   blind retaining-collar bore. Moving the front collar 10 mm forward, using
   M3x20 preload screws, shifting its pin axis 0.25 mm and providing a fully
   through bore for a Ø4x32 pin makes its withdrawal occur outside the coil.
3. **Brake anti-rotation:** two straight edges on the sliding adjuster flange
   engage the existing service-slot walls at both adjustment endpoints.
   The radial nut-loading slot extends through the keyed flange. Screw,
   spring, washer, captive nut and felt force paths remain intact.
4. **Mounted brake access:** four integral 24 mm feet leave the side and
   underside open to a short 2.5 mm hex key. Its actual B-rep fits the socket,
   clears a modeled bench and base through a 60-degree working stroke and
   inserts/removes sideways after disengagement. No bench access hole is
   required. Bench bolt allowance increases from bench thickness +18 mm to
   +42 mm for this module. The plate above the feet requires removable print
   support or a reviewed alternate slicer orientation.
5. **Flush frame mounting:** four M4x20 socket bolts now have actual heads,
   eight 0.8 mm washers and four 5 mm locknuts. The feet contact the base
   directly. Recessed head/lower-washer stacks react against 4.9 mm deep
   counterbores while retaining 0.1 mm nominal clearance above the Z=0 bench.
   Upper washers/nuts are accessible above each upright foot. The nominal
   20 mm shank reaches through the nut with positive thread projection.
6. **Strict types:** every `_mm` value must be a non-boolean real numeric
   value, finite and positive. Counts must be non-boolean integral types.
   Public frame/payoff validation occurs before cached construction so a
   numerically equal invalid dataclass (for example `rib_count=6.0`) cannot
   reuse valid cached geometry.
7. **Diameter labels:** physical cam engravings use the three validated
   diameter values rather than fixed strings. A non-default 112/128.5/144
   configuration is probed against the actual engraved CAD cuts and exported
   with matching configuration table, reference metadata and explicit
   `engraved_diameter_labels` in the manifest.

`windwall.winding_tool_service` contains isolated retention, mounting, tool
and removal gauges. The assembly audit consumes its five additional checks;
the drawing generator consumes the same physical removal stages. Existing
ownership, engagement, rotation, head hardware, tape and print audits remain
active. No mesh filtering, general healing or failure-status suppression was
introduced. The deterministic/fail-closed export path is preserved.

## Test-first evidence

Focused regressions were executed before their corresponding implementation:

| Issue group | Observed RED | Correction / focused GREEN |
| --- | --- | --- |
| Types and custom physical labels | 6 tests, 8.167 s: 13 failures and 16 errors; wrong types accepted or raised TypeError, custom glyph probes lacked cuts | Strict validation and generated glyphs; covered again by the final full tooling run |
| Axial retention, flush M4 stacks, brake keying and bench access | 4 tests, 11.599 s: 20 subtest failures; absent collars/caps; 25.1327 mm³ bolt/bench overlap; zero anti-rotation engagement; obstructed key/bench/socket | Positive collars/caps, complete recessed hardware, keyed flange, feet and socket |
| Complete service API and cached invalid count | 3 tests, 14.636 s: three failures | Real ordered service stages, physical audits, validation before cache |
| New printable cap inventory | 1 test, 15.503 s: complete-inventory coverage ValueError | One cap master with two congruent members; focused inventory regression green |
| Keyed adjuster nut service | First combined 19-test run retained four failures at 6–9 mm withdrawal | Extended the nut loading cut through the key; all 33 frame/payoff tests then reported OK in 13.968 s |
| Complete pin withdrawal | Route first found 0.02329059 mm³ collar-pin/preload-nut overlap, then 12.566 mm³ pin/collar overlap on withdrawal | Cleared the nut axis, moved the collar ahead of the coil, lengthened preload screws and opened the full pin bore |
| Custom export label inventory | 1 test, 389.952 s: `None != ['112', '128.5', '144']` | Added explicit manifest label values, retaining the separate physical glyph regression |
| Sealed 608 face exclusion | 1 test, 9.639 s: four failures; 12.2710609 mm³ seal/cap overlap and 1.26645454 mm³ seal/collar overlap under axial engagement | Ø10.4 mm noses and Ø20 mm shoulder/cap openings; all 39 frame/payoff/parameter tests OK in 14.041 s |

The additional sealed-bearing regression was prompted by a manufacturer-data
cross-check, not by a new review wave. The
[SKF 608-2RSH drawing](https://www.tme.eu/Document/83a59906c97cb2ff6c50c795411b45d2/SKF608-2RSH.pdf)
specifies a 10–10.5 mm shaft abutment and a maximum 20 mm housing-abutment
opening, with a 19.2 mm outer recess diameter. The preliminary Ø11 mm nose
and Ø18 mm housing relief were refined accordingly before commit. Tests use
an independent conservative flush annular exclusion for the sealed region.

After the collar/pin withdrawal change, the two focused full-route/service-negative
tests reported **OK, 2 tests, 234.486 s**. The route ran all three required
diameters against every stationary member. The audit rejected a locator
displaced 20 mm and a connected overhead obstruction in the supported lift.
An earlier diagnostic run predating the broad-phase/early-failure route
optimization was interrupted; it is not counted as verification.
Two incomplete final-suite attempts were also stopped when the sealed-bearing
refinement became necessary; the replacement complete runs are authoritative.

All geometry commands use:

```powershell
$env:PYTHONPATH = "$PWD;$PWD/src"
& 'C:/Users/fi87roy/Documents/GitHub/windwall/.venv/Scripts/python.exe' scripts/run_geometry.py ...
```

The native Windows/OCP interpreter can return status 1 after unittest prints
`OK` or after the CLI publishes its manifest. Application/test outcomes and
native process status are recorded separately; no clean shutdown is implied.

## Final verification

Final verification commands, all through the geometry launcher and the
interpreter/PYTHONPATH recorded above:

```powershell
& 'C:/Users/fi87roy/Documents/GitHub/windwall/.venv/Scripts/python.exe' scripts/run_geometry.py -m unittest tests.test_winding_tool_parameters tests.test_winding_head tests.test_winding_frame tests.test_wire_payoff tests.test_winding_tool_assembly tests.test_bearings -v
& 'C:/Users/fi87roy/Documents/GitHub/windwall/.venv/Scripts/python.exe' scripts/run_geometry.py -m unittest tests.test_winding_tool_export -v
& 'C:/Users/fi87roy/Documents/GitHub/windwall/.venv/Scripts/python.exe' scripts/run_geometry.py -m unittest tests.test_exports tests.test_release_index tests.test_run_geometry -v
```

The first command completed: **86 tests, OK, 1945.749 s**, native exit status 1.
All parameter, head, frame, payoff, assembly and bearing tests passed, with no
skips. This includes all three full diameter audits, the complete supported
removal route at each diameter, seal exclusion, actual fastener/bench stacks,
mounted hex-key access, anti-rotation, and negative displacement/obstruction
checks. No audit was patched out in the complete integration tests; isolated
component tests retain their explicitly documented construction-only patches.

The third command completed: **30 tests, OK, 147.127 s**, native exit status 1.
It covers unchanged V5 print sources, all unique part exports, manifold/STL
and STEP checks, canonical byte preservation through Git/Windows checkout,
shared failure publication, release-index hash bindings and launcher status
propagation.

The second command completed: **11 tests, OK, 2263.459 s**, native exit status 1.
All full-export, non-default diameter, unique-cap inventory, STEP reimport,
closed single-component STL, zero-degenerate-face, BOM/hash, drawing/guide
synchronization, CLI failure propagation, stale-manifest removal and fresh
artifact byte-equality cases passed. No cases were skipped.

**Final total: 127 passed, zero failures/errors, zero skips.** This includes
the complete 89-test tooling set, eight bearing tests and 30 shared regression
tests. Native process status was 1 after each successful unittest summary;
the application results are not represented as clean host-process shutdowns.

The tooling test inventory grew from 76 to 89 methods (13 new regressions).
Together with eight bearing and 30 shared-infrastructure tests, the final
commands cover 127 tests. The entire repository suite was not rerun during
this focused fix wave; the parent's Task 8 baseline covered 274 tests before
these 13 additions, with 22 documented skips. A whole-repository rerun, if
desired for integration, is `scripts/run_geometry.py -m unittest discover -s tests -v`.
No unrelated V5 document, external-reference or other CAD module is claimed
freshly verified beyond the explicitly listed regression commands.

### Real CLI rebuild and independent repeat

Executed the real CLI both for the release and for a separate, initially absent
output directory:

```powershell
& 'C:/Users/fi87roy/Documents/GitHub/windwall/.venv/Scripts/python.exe' scripts/run_geometry.py scripts/build_winding_tool.py
& 'C:/Users/fi87roy/Documents/GitHub/windwall/.venv/Scripts/python.exe' scripts/run_geometry.py scripts/build_winding_tool.py --output-dir build/final-review-repeat-release
```

Both final corrected builds published **14 unique print candidates and three
STEP assemblies**, followed by native process status 1. Resolved both exact
roots, enumerated relative paths, compared every file with
`[Linq.Enumerable]::SequenceEqual[byte]` and independently computed SHA-256:

```text
PASS: 37 identical corrected-release files; direct byte and SHA-256 equality; 38989420 bytes per tree
PASS: exact manifest inventory; 36 artifact hashes; 14 masters / 26 pieces; 44 hardware rows; source/release guide identical; 24 passing audit checks
```

The independent inventory check reconstructs manifest references from all part
STEP/STLs, assembly STEPs, supporting artifacts and BOM; verifies exact on-disk
inventory/no extras and every recorded hash; verifies every BOM row/quantity
appears in the guide; and compares source/release guide bytes directly.
The success manifest is absent until all release gates pass. All three final
corrected PNGs were again inspected at native resolution and are exactly the
repeat-build images. Final SHA-256 anchors:

- `manifest.json`: `b4832952b389273142bf91be39d9fc30e3e13e502b8669f09d4d37b78e719ec4`
- `bom.json`: `8da546d95d6d1f9845c1d2fea2671d70a020876311f3ad6da0ae9697aac8b304`

The final guide also explicitly keeps the head unpinned until the shaft has
been threaded through the already-mounted bearings and supported head stack.
Both CLI builds were repeated after this guide-only clarification. Their
three PNG hashes remain identical to the full-resolution images inspected
after the sealed-bearing correction:

- Reference: `b1f80a5719331b54c0ec5c3055205fc3981437f1b6a67b20a494f7d456697a40`
- Range/removal: `42c0e2f8efa5c9dee82689988d7666cbc22ee387b588aaaacecd7d3ec4a6fca8`
- Exploded: `798ab182b024977044f19b64cb9e173bb098177d6b658a3200b6574117376053`

After direct-byte/hash equality, the exact absolute
`build/final-review-repeat-release` path was resolved and checked against
the expected worktree and its prefix before native PowerShell recursive
removal. Only the verified duplicate rebuild was removed; the identical
release remains. The temporary collar-interference probe was also removed.

The final reference assembly audit has **24 passing checks**, no errors/collisions,
six ribs, 18 tape stations, 12 mm minimum tape clearance, 210 mm maximum X/Y
print envelope, 2 mm radial release, 1 mm rigid brake clearance and
14.76482306032329 mm crank-hand clearance. New service evidence records both
0.1 mm collar face gaps, 0.1 mm upright-fastener bench clearance, 14.5 mm
brake-key bench clearance and zero coil-removal collisions.

### Hygiene and isolation

`git diff --check` passes. A separate trailing-tab/space scan over all 16
changed source/test/doc files passes. Python AST parsing of all 14 changed
Python files found no unused-import candidates; the public service-stage
re-export uses an explicit same-name alias. The placeholder/unsupported
physical-or-powered-success scan found no matches. No obsolete source,
dependency or production configuration remained to remove.

`git diff --exit-code 0fbebe9 -- src/windwall/export.py scripts/build_v5.py release/v5`
is empty and returns zero. Existing `PRINT_SOURCES` and V5 production inventory
remain unchanged. Generated STEP bytes were not normalized or filtered.

After staging, `git diff --cached --check` and `git diff --check` both pass.
An independent comparison of `git ls-files release/winding-tool` with the
on-disk tree confirms all 37 release files are staged/tracked, without extras.
At that check, there were zero unstaged tracked changes and zero untracked
non-ignored files; the ignored report is explicitly force-added after final
results are recorded. The initial sandboxed staging attempt could not write
the shared Git index; the approved scoped Git escalation succeeded. No
repository setting, existing index data or unrelated work was discarded.

## Inventory and documentation

The cap adds **one unique print master and two printed pieces**: 14 masters,
26 pieces total. Six added hardware rows bring the hardware inventory to 44.
The release contains 37 files: 14 STEP/STL pairs, three assembly STEPs,
three PNGs, German guide, BOM and manifest.

Changed source: parameters, head, frame, payoff, assembly, export and the new
service-audit module. Changed tests: all six tooling test modules. The preview
script renders the revised hardware and full removal stages. Updated both
`docs/winding-tool-assembly.md` and the German source/release operator guide,
including hardware tables, assembly order, bench clearances, feet/supports,
keeper removal, supported head handling, free workspace and measured limits.
All affected release artifacts are regenerated; no V5 artifact or production
`PRINT_SOURCES` entry is changed.

## Visual inspection

Opened all three regenerated PNGs with `view_image`, `detail: original`, at
their native **2000 x 1400** resolution:

- **Reference:** two independent modules, shaft/manual crank, new bearing
  caps/left locator note, four payoff feet, bench and inserted short key are
  clear. The B-to-A wire arrow and legend remain readable without clipping.
- **Range/removal:** three head settings retain all 18 numbered tape stations.
  Below them, actual CAD snapshots show the 220 mm shaft pull, 200 mm head
  lift and final 50 mm axial coil exit. The brown annulus is distinguished
  from the head, and the caption states its finite axial/radial/tape bounds.
  Keeper/pin handling, helper support and unchanged uprights/caps are explicit.
- **Exploded:** both caps and the two left metal collars appear with the 608
  group. New feet remain visible under the payoff base. Labels distinguish
  one complete 51105 from its three motion members. The fastener groups and
  1–15 callouts are legible; this remains a grouped, not individual-fastener,
  explosion. No label is clipped or overlaps another text block.

All drawings retain their prototype/physically-unchecked footer and the exact
warning: **Akkuschrauberbetrieb ist nicht freigegeben**.

## Limitations and handoff

These are CAD-verified workshop prototypes, not validated machines. Printed
strength, supports, wear, actual bearing lands, pin fits, endplay, stiffness,
retainer keeper selection, spring properties, useful brake drag, enamel
protection, electrical properties and cassette fit require physical trials.
The contact circles remain default Ø110–145 with a calculated Ø127 reference.
The 6.35 mm hex interface remains future-only; powered operation is unapproved.
Motion/translation checks sample positions, not continuous certified sweeps.
Hands/support fixtures and detailed purchased keeper clips are not modeled.
Coil removal requires the documented helper and clear workspace.

All seven final-review findings are implemented and verified within this
single fix-wave commit. The staged change contains 38 focused files, including
this report and the synchronized generated artifacts. The next decision is
the parent's final review/integration; no merge or push was performed.

Commit subject: `fix: make winding tool serviceable`. The containing commit
hash and clean post-commit status are supplied in the parent handoff after
fresh Git checks; this report avoids a self-referential commit hash.

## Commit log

2026-09-08 docs: define parametric Ugrinsky rotor design
2026-09-08 docs: plan parametric Ugrinsky rotor implementation
2026-09-08 chore: establish parametric CAD project
2026-09-08 test: automate source STL quality audit
2026-09-08 test: add reference audit dependency and fixture
    [tetrahedron_binary.stl]
2026-09-08 feat: reconstruct clean Ugrinsky blade stage
2026-09-08 feat: add blade drivers and joint retainers
2026-09-08 feat: build modular seven-stage rotor parts
2026-09-08 feat: reconstruct dual magnet rotor generator
2026-09-08 feat: assemble seven-stage Ugrinsky rotor
2026-09-08 build: export and validate printable rotor parts
2026-09-08 fix: seat locked rotor before retainer loading
2026-09-08 fix: verify printed axial seating contact
2026-09-09 docs: design Ugrinsky assembly manual
2026-09-09 docs: plan illustrated assembly manual
2026-09-09 feat: define assembly manual data model
2026-09-09 feat: render manual exploded CAD drawings
2026-09-09 fix: classify and route manual CAD callouts
2026-09-09 feat: illustrate magnets and serpentine winding
2026-09-09 fix: clarify electrical manual schematics
2026-09-09 feat: build German Ugrinsky assembly manual
2026-09-09 feat: retain V4.3 modular rotor prototype
2026-09-09 docs: specify V5 generator housing and bearing system
2026-09-09 docs: plan V5 generator housing implementation
2026-09-09 feat: model 51105 and 608 bearing fits
2026-09-09 feat: add stationary generator housing and coil cassette
2026-09-09 feat: integrate enclosed dual-rotor generator
2026-09-09 fix: audit installed generator shaft washer
2026-09-09 fix: keep top support above recessed clamp stack
2026-09-09 build: export complete V5 windwall release
    [25mm_pilot_coupon.step, 25mm_pilot_coupon.stl, 51105_outer_seat_coupon.step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]
2026-09-09 docs: publish V5 generator assembly manual
2026-09-09 fix: clarify V5 magnet polarity and validation boundaries
2026-09-10 docs: clarify rotor motion in English and Hindi manuals
2026-09-10 feat: refine generator coil cassette and rotor spacer
    [coil_cassette.step, coil_cassette.stl, fence_assembly.step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]
2026-09-10 docs: specify V5.2 rotor seams and visuals
2026-09-10 plan: implement rotor seams and visual publishing
2026-09-10 fix: support base blade roots from the print plane
2026-09-10 build: regenerate V5.2 rotor artifacts
    [base_rotor_module.step, base_rotor_module.stl, bayonet_female.step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]
2026-09-10 docs: add ten-rotor windwall presentation media
2026-09-10 docs: publish canonical English assembly drawings
2026-09-11 fix: restore thin base plate and flush bayonet receiver
    [base_rotor_module.step, base_rotor_module.stl, bayonet_female.step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]
2026-09-14 fix: flatten generator cover underside
    [fence_assembly.step, generator.step, generator_cover.step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]
2026-09-14 docs: specify base bearing labyrinth
2026-09-14 docs: plan base bearing labyrinth implementation
2026-09-14 feat: shield base bearing with labyrinth cup
2026-09-14 release: publish base bearing labyrinth geometry
    [base_rotor_module.step, base_rotor_module.stl, fence_assembly.step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]
2026-09-14 docs: document base bearing labyrinth
2026-09-14 docs: specify flat lower rotor and plain blade ends
2026-09-15 docs: plan flat rotor and plain blade ends
2026-09-15 feat: flatten lower magnet rotor print surface
2026-09-15 feat: join rotor stages with plain blade ends
2026-09-15 release: publish flat lower rotor and plain blade ends
    [base_rotor_module.step, base_rotor_module.stl, fence_assembly.step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]
2026-09-15 docs: explain flat lower rotor and plain blade joints
2026-09-15 feat: add manual winding frame and crank
2026-09-15 fix: clear crank and couple winding head
2026-09-15 fix: add captive preload nut interfaces
2026-09-15 feat: add 51105 wire payoff turntable
2026-09-15 fix: complete payoff brake load path
2026-09-15 feat: assemble and audit winding tools
2026-09-15 stronger bajonett
    [base_rotor_module.step, base_rotor_module.stl, bayonet_female.step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]
2026-09-15 fix: verify bearing and follower engagement
2026-09-15 docs: publish serpentine winding tool release
    [winding_frame_base.step, winding_frame_base.stl, winding_frame_crank.step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]
2026-09-15 fix: make winding tool serviceable
    [winding_frame_base.step, winding_frame_base.stl, winding_frame_bearing_cap.step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]
2026-09-16 docs: specify simple pin-adjustable coil winder
2026-09-16 docs: plan simple pin-adjustable coil winder
2026-09-16 refactor: define simple coil wheel parameters
2026-09-16 feat: add pin-adjustable coil wheel
2026-09-16 feat: add screwless printed wheel stand
2026-09-16 fix: clear bearing clip withdrawal paths
2026-09-16 refactor: simplify free-running wire payoff
2026-09-16 fix: validate completed payoff print envelopes
2026-09-16 refactor: assemble simple winding tools
2026-09-16 docs: publish simple coil winder release
    [free_running_wire_payoff.step, winding_frame_base.step, winding_frame_base.stl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]
2026-09-16 fix: clear full-width tape during shoe removal
    [winding_jig_contact_shoe.step, winding_jig_contact_shoe.stl]
2026-09-17 feat: add asymmetric wire cradle to winding shoes
2026-09-17 docs: publish asymmetric winding shoe release
    [winding_jig_contact_shoe.step, winding_jig_contact_shoe.stl]
2026-09-22 fix: strengthen winding shoe friction fit
    [winding_jig_coil_wheel.stl, winding_jig_contact_shoe.step, winding_jig_contact_shoe.stl]
2026-09-22 fix: center winding labels and tighten shoe fit
    [winding_jig_coil_wheel.stl, winding_jig_contact_shoe.step, winding_jig_contact_shoe.stl]
2026-10-05 feat: release horizontal winding-tool CAD and assembly drawings
    [winding_jig_base.step, winding_jig_base.stl, winding_jig_bearing_retainer.step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]
